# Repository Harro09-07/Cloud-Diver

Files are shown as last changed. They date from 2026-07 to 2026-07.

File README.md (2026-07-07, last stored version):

#Cloud Diver

A (planned to be) Semiautonomous drone designed to sample otherwise inaccesible parts of weather systems utilizing a novel wing folding design allowing rapid dives through adverse wind conditions that would otherwise damage or destroy a conventional aircraft or drone.

Current Features:
Total BOM cost of less that 200 dollars (support equipment excluded)
A full length "keel" and internal flexible spars to allow flight even after heavy damage
A foldable wing design built using simple components, mainly steel hinges, fishing line, and a 20kg strength servo motor
A payload bay with support for temperature, humidity and barometric pressure sampling as well as a camera for visual observation.
Oversized full moving combination Elevator, rudder, and aileron control surfaces for extreme control authority in all phases of flight
A modular design built around individual sections fitted together on 2mm steel rods.

In Progress features:
A bleed air system to allow even greater takeoff with wings extended and flight control with wings retracted
Additional modules, including a mechanism to allow launch from other flight platforms

Planned Features:
Deformable wings to allow greater control authority
Autonoumous "Return to home" capability in case of signal loss
Wind speed and direction monitoring, as well as percipitaion detection.

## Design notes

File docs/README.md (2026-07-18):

# Cloud Diver



## Overview: 
A (planned to be) Semiautonomous drone designed to sample otherwise inaccesible parts of weather systems utilizing a novel wing folding design allowing rapid dives through adverse wind conditions that would otherwise damage or destroy a conventional aircraft or drone.

### Current Features: 
Total BOM cost of less that 200 dollars (support equipment excluded)

A full length "keel" and internal flexible spars to allow flight even after heavy damage 

A foldable wing design built using simple components, mainly steel hinges, fishing line, and a 20kg strength servo motor

A payload bay with support for temperature, humidity and barometric pressure sampling as well as a camera for visual observation.

Onboard Data processing via Arduino

Oversized full moving combination Elevator, rudder, and aileron control surfaces for extreme control authority in all phases of flight

A modular design built around individual sections fitted together on 2mm steel rods.

### In Progress features: 
A bleed air system to allow even greater takeoff performance with wings extended and flight control with wings retracted

Additional modules, including a mechanism to allow launch from other flight platforms

### Planned Features: 

Deformable wings to allow greater control authority 

Autonoumous "Return to home" capability in case of signal loss

Wind speed and direction monitoring, as well as precipitation detection.

## Purpose
As it stands, the only way to collect data on the inside of storms is via expensive and complex doppler radar systems, this project aims to change that with an accessable and cheap platform by which to gather data at the source

## Notes
Assembly is straight forward, the rods pass through 3 identical holes on each part and then all parts snap together using the inbuilt pegs.
See the electronic mounting locations for information on intended mounts for non printed components.

## Current Prototype: Version 1.5 "Minima"



Based on a mix of version 1 and 2 cad components, "minima" represents the minimum viabke product for flight testing, incorporating onboard sampling electronics. Used for weight and balance testing, wing design validation, and soon initial flight testing.

(note: V1 was intended to be the full assembly of the V1 cad, as V1 cad was superceded prior to completion, v1 was scrapped and parts rolled into v2)

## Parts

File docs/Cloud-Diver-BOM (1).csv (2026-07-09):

"BOM"
"Approx 2 KG of PLA (generic, already owned)"
"5 450mm by 2mm steel rods (already owned)"
"1 50mm EDF Fan (sized for this one https://www.amazon.com/Brushless-Lightweight-Pre-Soldered-Connectorsa ircraft/dp/B0CD7X9RNG?crid=1QXPGUUE0HVT3&dib=eyJ2IjoiMSJ9.9eWqwI9SUSxwR8uXEHIeTNxKp9_8fvUBtexAhzLWORfc0iQkZJ-oeU77wthYdITLe7zFL6alS7gMDzUyNpt6cVDvSKxUnjUGvePuAMhZU4e1o-S-QvdeqL96wBx91f9nPJoTUihM2RFX2m1GrdNTxbXDUWlfRE2ca5vH1Wj18u7PVmbTKiBYNVl42YcRWFRvtM9hkIi0xC_bV5XkZQkNn9JNHCdSzQ1LJJsE7XnKvlZoGL8GpicpBNu47SrjV9-aAGhlWTNJ71KGBtwLoNyjzz5907Qj-1Lej73fORdG14c.EfKWftGZaflVe2bddr4Rv8CrGzhoAgslBFNTk5EhkFs&dib_tag=se&keywords=edf&qid=1783454560&sprefix=ed%2Caps%2C333&sr=8-3) (already owned)"
"1 19x19 FPV camera (https://www.amazon.com/FPV-Camera-RunCam-Phoenix-FOV160%C2%B0Global/dp/B0BQ2FVKWN (already owned)"
"1 4s ESC (https://www.amazon.com/Brushless-Controller-Airplanes-Multi-axis-Helicopter/dp/B0CN317H74 ($12.99)"
"3 1in steel hinges (https://www.amazon.com/Piutouyar-Stainless-Cabinet-Folding-Mounting/dp/B09LHJ95YS ($4.99)"
"1 Temp/humidity sensor (https://www.amazon.com/EC-Buying-Temperature-Measurement-Communication/dp/B0BXDMJDK8 ($16.99)"
"1 Pressure sensor ( https://www.amazon.com/ACEIRMC-Temperature-Barometric-Pressure-Arduino/dp/B091GWXM8D ($6.99)"
"1 4s Battery with xt60 (https://www.amazon.com/OVONIC-Battery-2200mAh-14-8V-Connector/dp/B0DFM9VXQZ ($45.99)"
"1 ELRS Receiver (https://www.amazon.com/Radiomaster-ExpressLRS-Receiver-Fixed-Wing-Aircraft/dp/B0DY73VYMQ/140-5065120-1921429 ($43.99)"
"1 ELRS Transmitter (Radiomaster Pocket) (already own)"
"1 arduino (https://www.amazon.com/Arduino-UNO-WiFi-ABX00087-Bluetooth/dp/B0C8V88Z9D ($27.50)"
"3 9g Servos (already owned)"
"1 20kg servo (https://www.amazon.com/Treedix-MG996R-Servo-High-Torque-Helicopter/dp/B08743N181 ($15.99)"
"1 M3 heated insert (already owned)"
"1 m3 bolt (about 16 mm) (already owned)"
"Fishing line (already Owned)"
"Dupont Wiring (https://www.amazon.com/Elegoo-EL-CP-004-Multicolored-Breadboard-arduino/dp/B01EV70C78/140-5065120-1921429 (already owned)"
""
"Total Cost: $175.43"

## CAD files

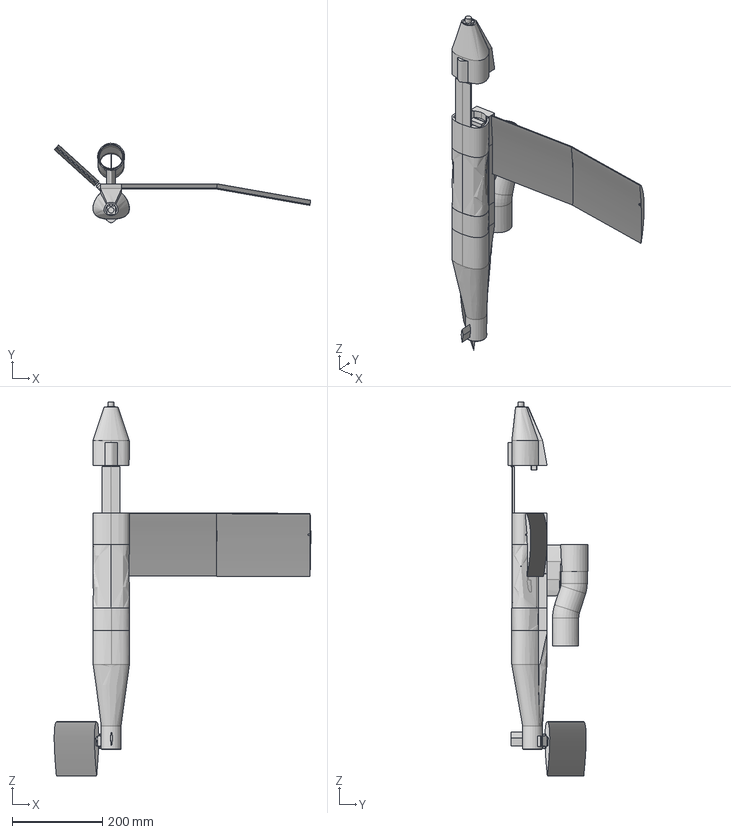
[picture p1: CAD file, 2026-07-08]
Optional Components/Cloud Diver Assembly.step
567.4 x 176.0 x 827.1 mm
wingbox segemnt
Outer WIng Segment
servo x 2
splined-drive x 2
horn x 2
inner wing segment
nose cone
tailbox
Rudderon (servo horn variant)
Cloud Diver Battery Compartment
Cloud Diver Payload Bay
Cloud Diver Electronics bay
FPV camera blank

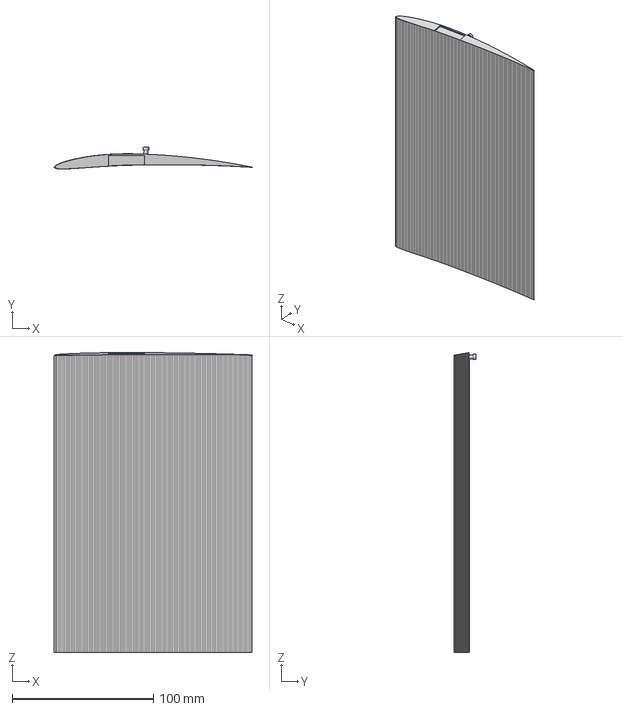
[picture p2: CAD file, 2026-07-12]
Essential Components/inner wing segment.step
140.5 x 15.6 x 212.1 mm

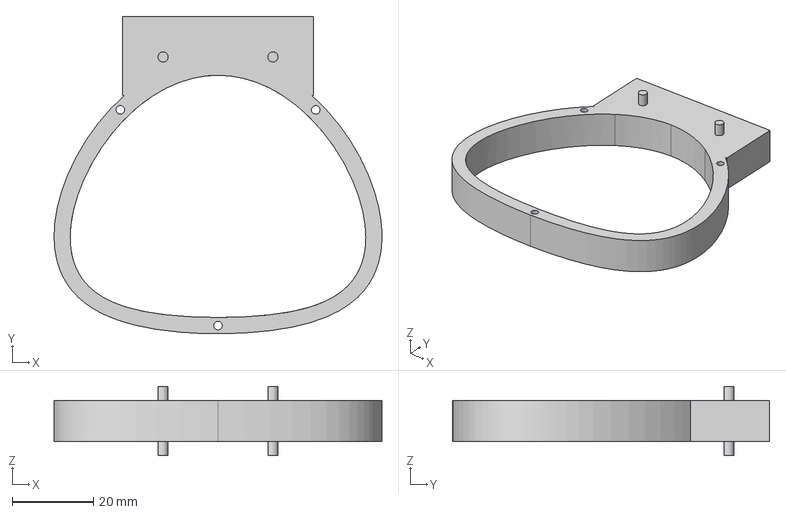
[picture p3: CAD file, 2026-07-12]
Optional Components/Cloud Diver nose_battery spacer.step
80.6 x 78.0 x 17.0 mm

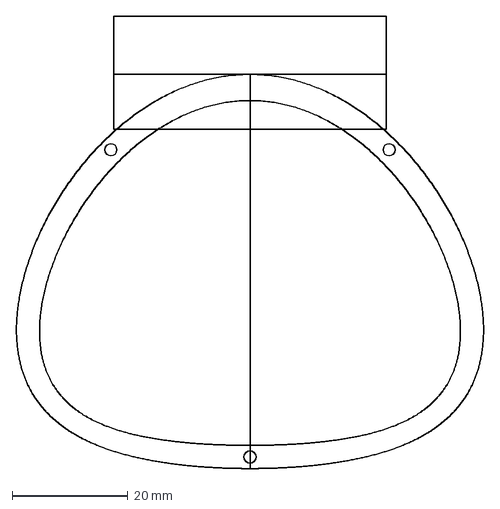
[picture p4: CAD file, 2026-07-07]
Sketches/wing box fuselage.dxf
80.6 x 78.0 mm

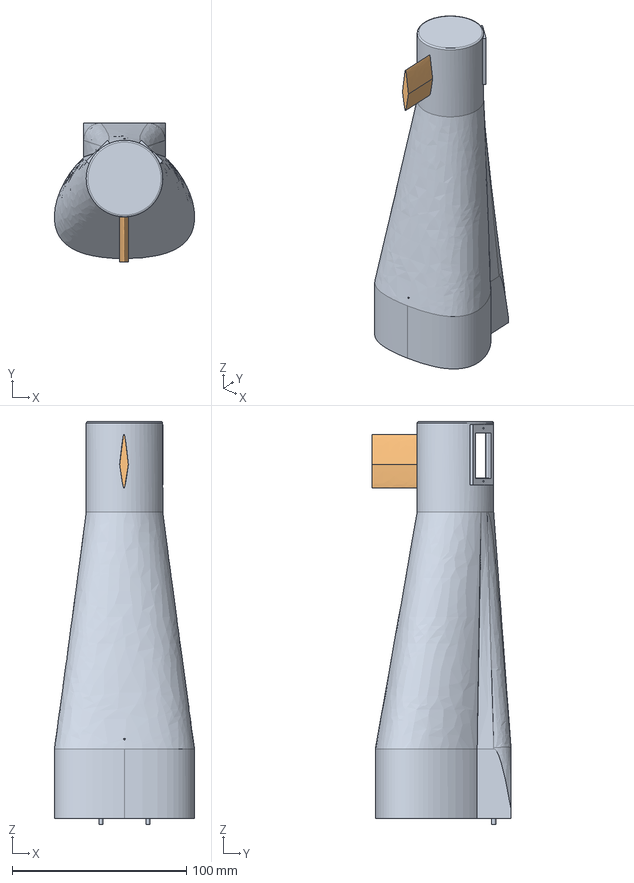
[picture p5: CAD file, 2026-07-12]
Essential Components/tailbox.step
80.5 x 80.0 x 231.5 mm

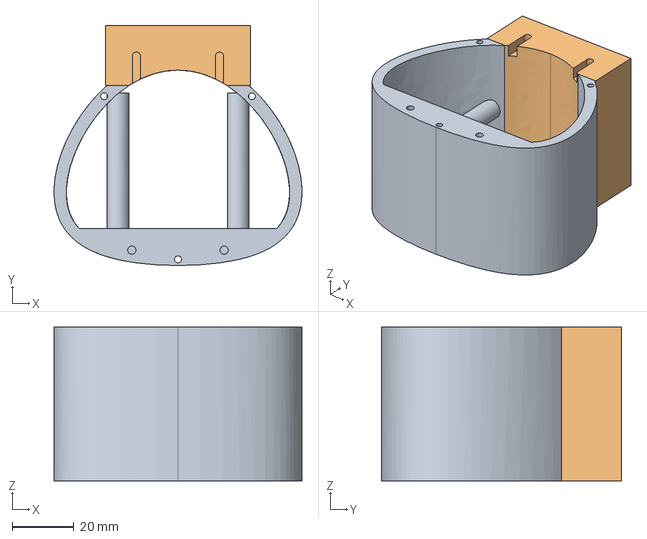
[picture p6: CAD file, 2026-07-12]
Optional Components/Cloud Diver Battery Compartment.step
80.6 x 78.0 x 50.0 mm

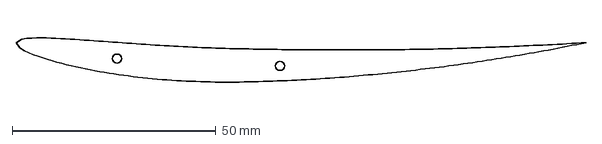
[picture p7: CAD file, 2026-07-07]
Sketches/wing profile.dxf
140.0 x 10.9 mm

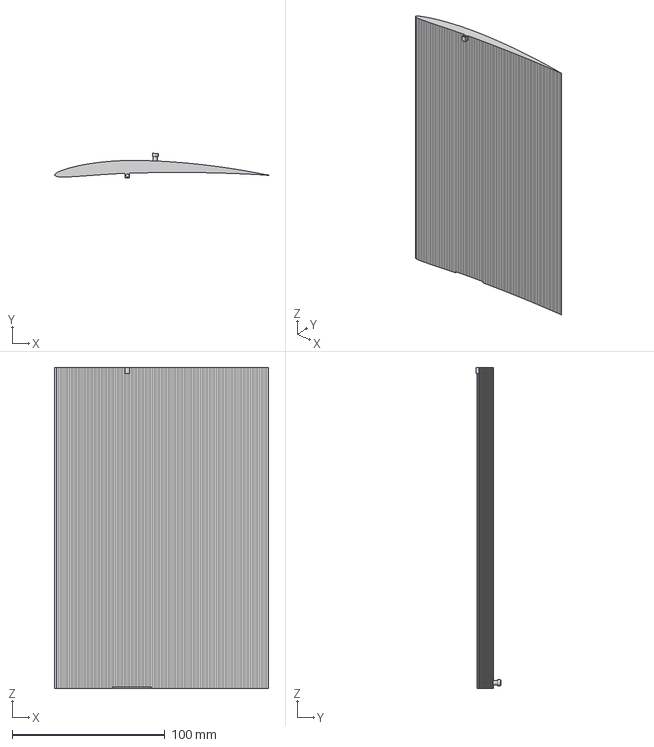
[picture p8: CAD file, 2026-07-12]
Essential Components/Outer WIng Segment.step
140.0 x 16.1 x 210.0 mm

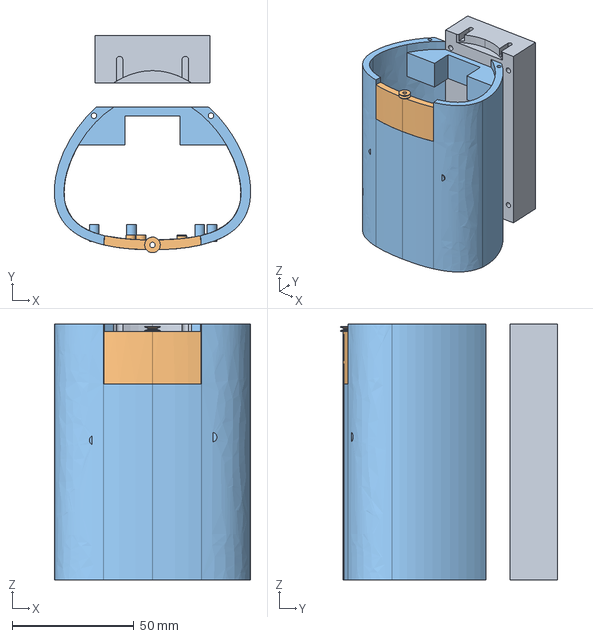
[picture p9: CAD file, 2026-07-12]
Optional Components/Cloud Diver Payload Bay.step
80.5 x 89.2 x 105.0 mm

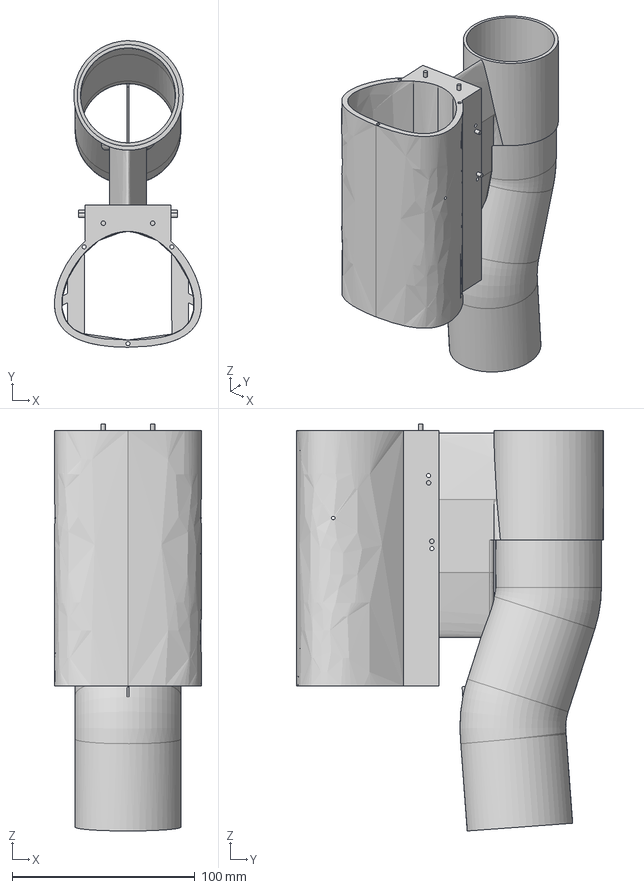
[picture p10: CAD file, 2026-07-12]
Essential Components/wingbox segemnt.step
80.6 x 168.0 x 223.0 mm

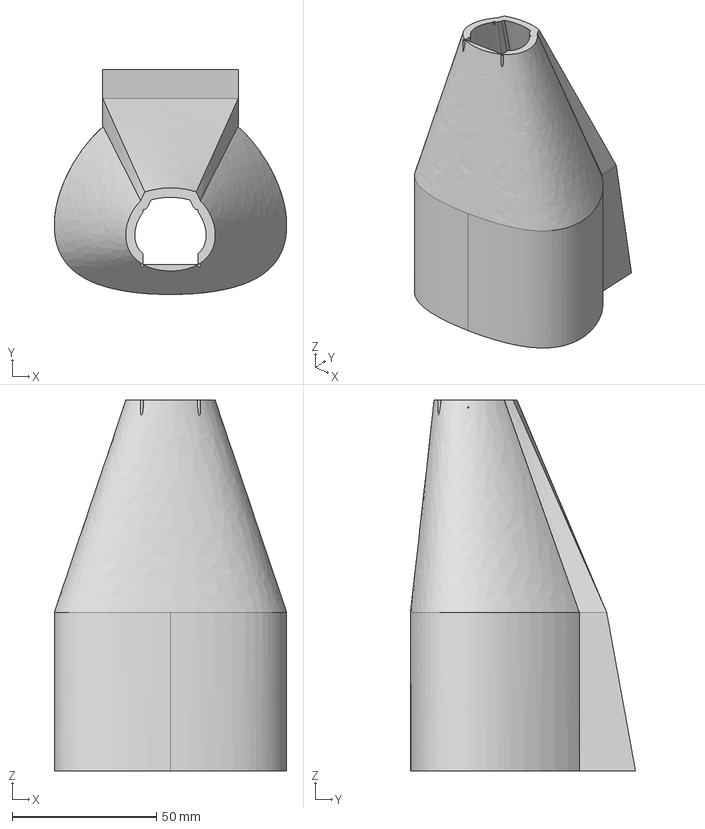
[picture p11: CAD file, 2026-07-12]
Essential Components/nose cone.step
80.5 x 78.0 x 128.5 mm

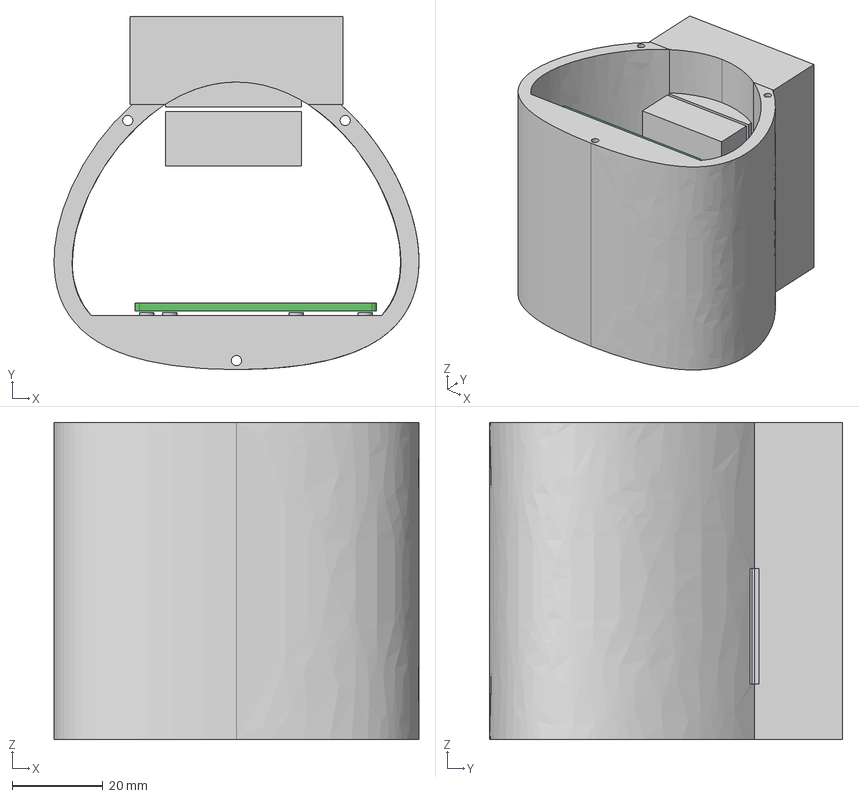
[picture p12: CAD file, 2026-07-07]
Optional Components/Cloud Diver Electronics bay.step
80.6 x 78.0 x 70.0 mm

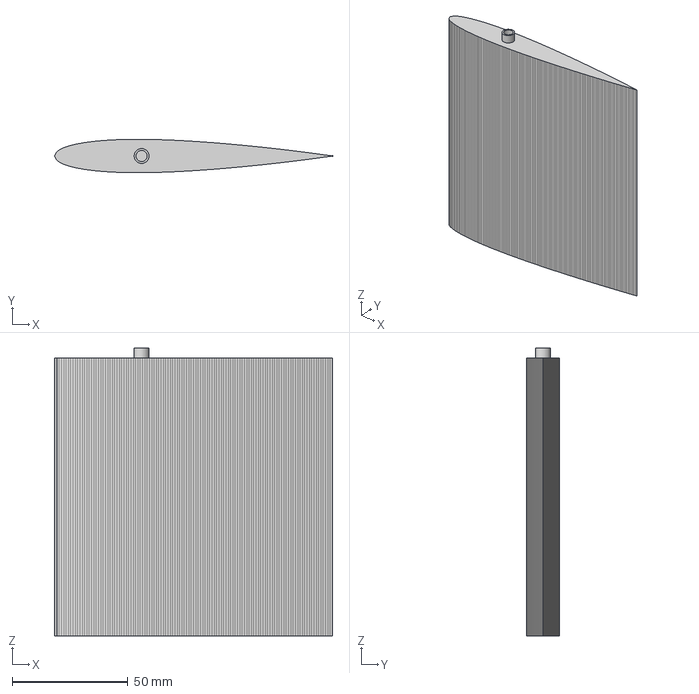
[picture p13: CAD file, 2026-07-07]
Essential Components/Rudderon (servo horn variant).step
120.0 x 14.4 x 124.3 mm

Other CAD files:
Essential Components/Outer WIng Segment.stl
Essential Components/Rudderon (servo horn variant).stl
Essential Components/inner wing segment.stl
Essential Components/nose cone.stl
Essential Components/tailbox.stl
Essential Components/wingbox segemnt.stl
Optional Components/Cloud Diver Battery Compartment.stl
Optional Components/Cloud Diver Payload Bay.stl

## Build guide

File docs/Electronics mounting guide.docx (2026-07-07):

Locations and mounts for electronics:

Rudderon Servos:

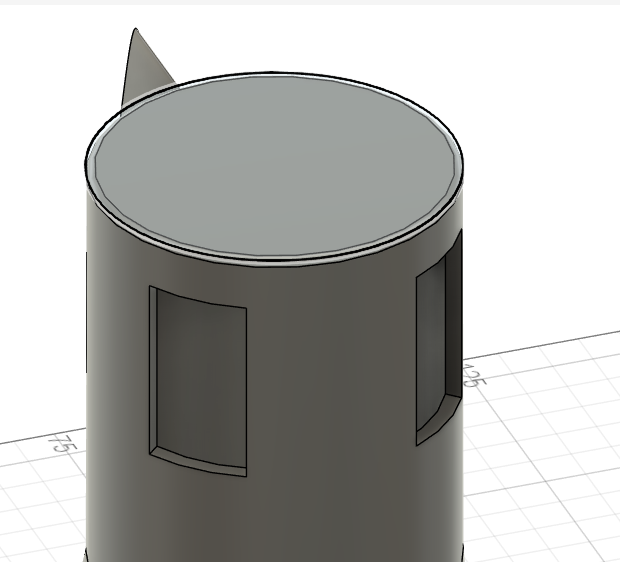
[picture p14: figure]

Payload sensors:

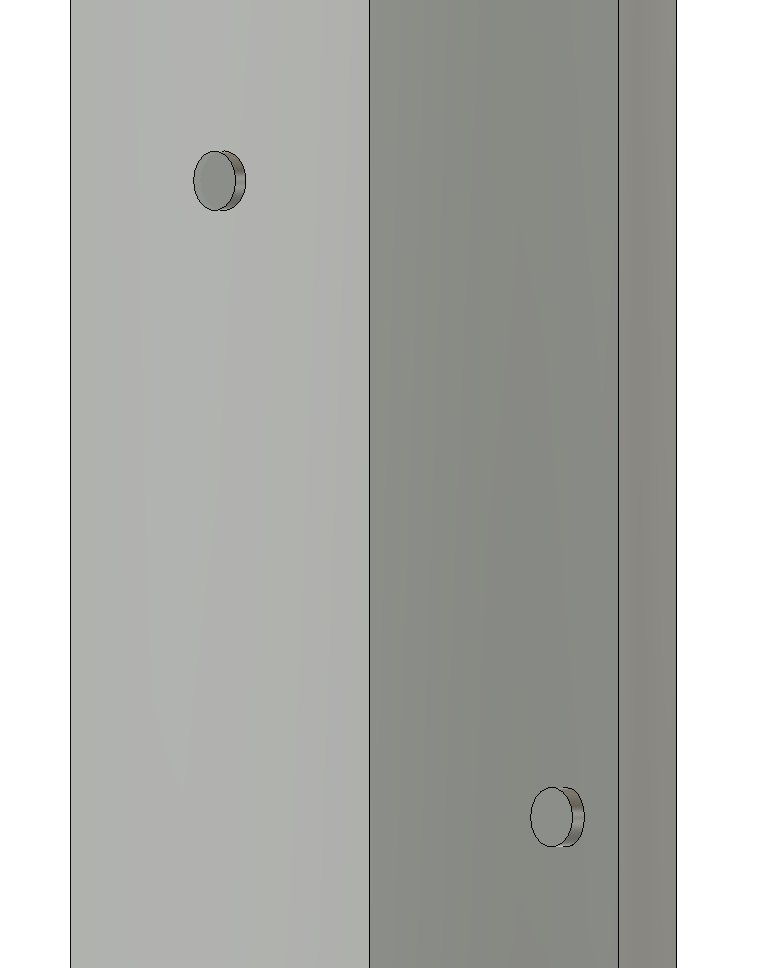
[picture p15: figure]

Payload Bay Servo:

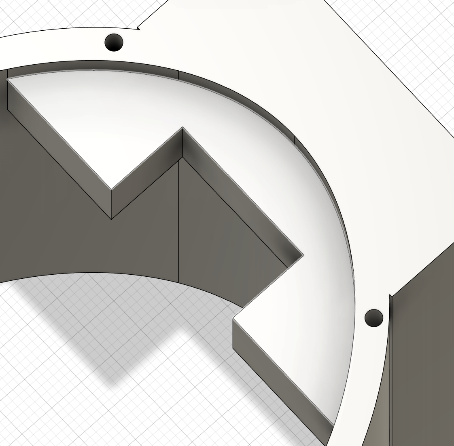
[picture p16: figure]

Wingbox Servo:

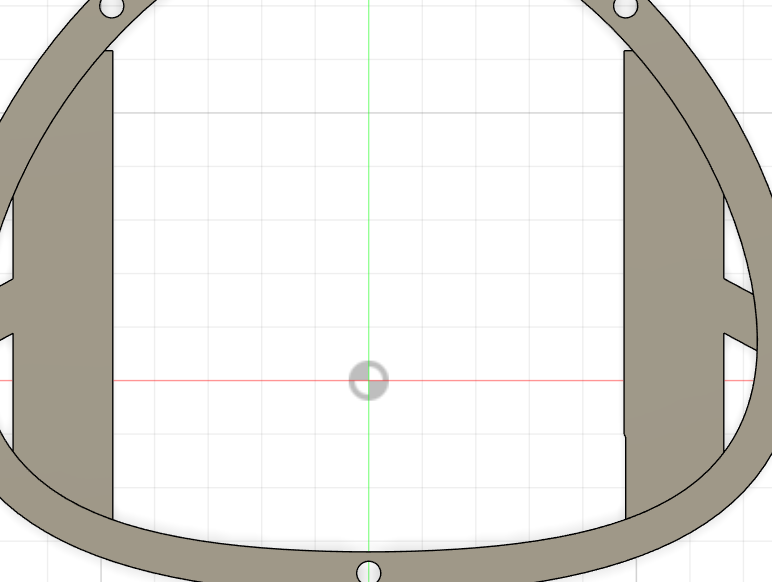
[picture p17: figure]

Camera:

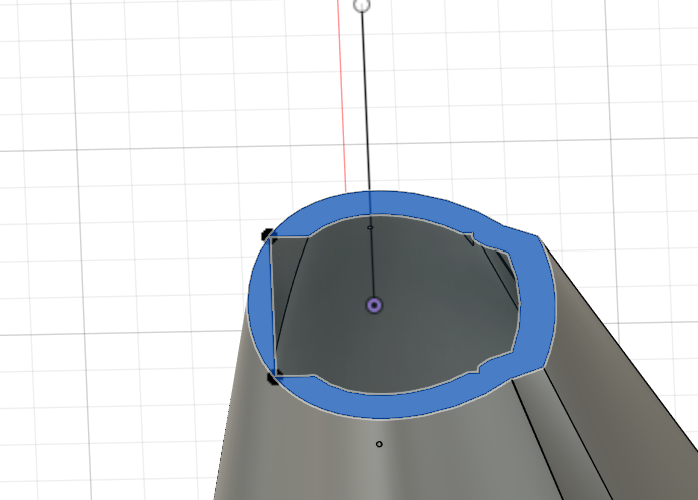
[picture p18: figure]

Reciever and Arduino:

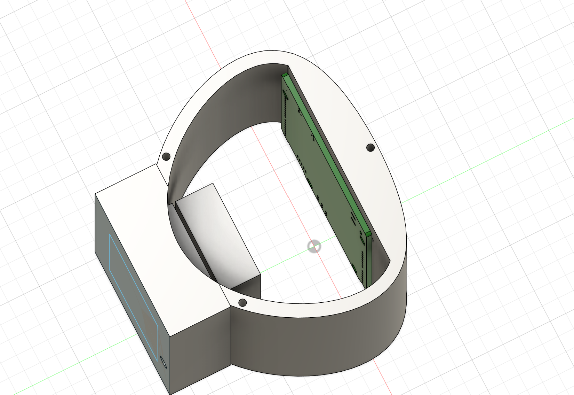
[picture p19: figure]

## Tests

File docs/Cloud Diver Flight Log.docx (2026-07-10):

Cloud Diver Flight Log:

Ground test 1:

Roll and Pitch control working, yaw control not so much (not sure it will ever work, might not need it)

EDF Working well, though even with deflector piping the thrust is quite off axis.

Flight test 1:

Roll and pitch working, pitch trimmed to minimum to hopefully offset off axis thrust.
EDF run up acceptable.

Note: outer wing segments not in place. Not final flight hardware, most electronics uninstalled or replaced with subpar replacements.

Goal: prove flight capability

Launch type: thrown

Result: crash

Reason: combination of pilot overload (unable to manipulate thrust, roll and pitch while launching aircraft), insufficient lift (unknown if due to stall, or simple lack of wing area), off axis thrust forcing nose down attitude.

Damage: EDF unseated but working, transmitter disconnected, aft section of tail broken off with 5 holding pins sheared, remaining two holes damaged, Elevons detached but were not damaged, main frame bent by approximately 5 degrees, right wing bent at 45 degrees between first and second wing segment. All parts designed to hold electronics survived with minimal damage.

Notes: based on scuffing and damage indicators, first point of contact was the rear corner of the right wing, indicating a nose up attitude at time of crash, meaning some amount of control authority was being exerted.

Rectification: Outer wing segments will be added before next test flight, landing gear will be added to the nose cone and aft wing box, new deflector piping will be made to deflect the thrust through the center of gravity, additional reinforcement will be added in the form of friction fit pegs between segments, tail will be redesigned to allow easier and more consistent mounting of elevon servos, general structural reinforcement needed- bolt on package ideal. Flight computer for decrease pilot workload advisable.

Successes: individual subassemblies work, overall design needs very limited changes, printed components held up well, no major damage despite crash.

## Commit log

2026-07-07 Enhance README with Cloud Diver project details
    Added detailed description of the Cloud Diver drone, including current, in-progress, and planned features.
2026-07-07 Add note about optional battery bay component
2026-07-07 Add note about optional battery bay recommendation
2026-07-07 Update Note with details on Rudderons and wing segments
    Added notes about the Rudderons and wing segments.
2026-07-12 Update README with current prototype details
    Added current prototype information and image to README.
2026-07-12 Update README with prototype version details
    Added description for current prototype version.
2026-07-12 Clarify description of current prototype as 'knockoff'
2026-11-01 Add new image and details for prototype version 2.5
    Updated the README to include a new image and clarify the prototype version.
2026-11-01 Update Flight Log with test results and rectifications
    Documented results of multiple ground and flight tests, including successes and failures, along with proposed rectifications for future tests.
2026-11-01 Update README with new feature for wings
    Added mention of Vase Mode printable wings for quicker repair and replacement.
